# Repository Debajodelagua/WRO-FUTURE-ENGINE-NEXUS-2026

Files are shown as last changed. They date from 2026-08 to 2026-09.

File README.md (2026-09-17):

# 🏎️ WRO 2026 Future Engineers – Team Nexus
<div align="center">
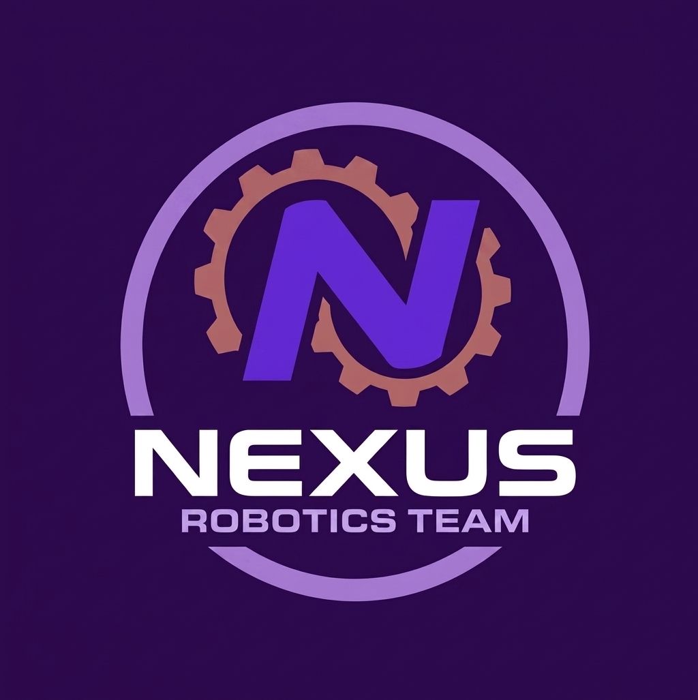
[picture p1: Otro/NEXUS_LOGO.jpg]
Team Nexus Autonomous Vehicle
  
  
  <br><br>
  
  
  
  <br>
  
  
  
  
  <br>
  
  
  
  <br>
  
  

</div>

Nuestro prototipo **"Smoke"** es un vehículo autónomo diseñado para la categoría **Future Engineers de la World Robot Olympiad™ (WRO) 2026**. 
Este documento técnico ha sido elaborado bajo un formato de **libro blanco de ingeniería (*Engineering Whitepaper*)**: no se limita a describir el resultado final, sino que expone de forma analítica y reproducible el **porqué detrás de cada decisión técnica**, los compromisos de diseño (*trade-offs*), los cálculos físicos y la evolución experimental del proyecto. Cualquier equipo o investigador que consulte esta documentación podrá comprender a profundidad los fundamentos cinemáticos, térmicos, eléctricos y de software que rigen el vehículo, permitiendo reproducir o iterar la plataforma de forma integral.

## 📑 Índice General: Módulos de Ingeniería del Proyecto

- [Introducción y Datos del Equipo](#introduccion-equipo)
  - [Filosofía de Trabajo y Metodología de Co-Diseño](#filosofia-trabajo)
  - [Nuestro Equipo (INIAR)](#nuestro-equipo)
  - [Estructura del Repositorio y Ficha Técnica Oficial (225 × 170 × 110 mm, 859 g)](#ficha-tecnica)
  - [Galería de Inspección Técnica 360°](#fotos-360)
  - [Videos Oficiales de Demostración (Open & Obstacle Challenge)](#videos-oficiales)

---

### [Módulo 1: Movilidad y Diseño Mecánico](#modulo-1-movilidad)
- 1.1 [Chasis Modular Multicapa en PETG y Distribución de Masa](#chasis-petg)
- 1.2 [Estructura Rígida, Tornillería Pasante M3 y Separación de Niveles](#separacion-niveles)
- 1.3 [Geometría de Dirección Ackermann Híbrida y Validación de Barrido](#geometria-ackermann)
- 1.4 [Tren Motriz Trasero (RWD), Transmisión Cónica y Caja Diferencial](#tren-motriz)
- 1.5 [Estudio Dinámico: Razonamiento de Par Motor vs. Velocidad](#estudio-dinamico)
- 1.6 [Configuración Escalonada de Ruedas (*Staggered Setup*) e Inercia Rotacional](#ruedas-escalonadas)
- 1.7 [Diseños Alternativos Considerados vs. Diseño Mecánico Elegido](#alternativas-mecanicas)
  - 1.7.1 [Evolución Cronológica y Autopsia Técnica de Prototipos Descartados](#prototipos-descartados)

---

### [Módulo 2: Arquitectura de Energía y Sensores](#modulo-2-energia-sensores)
- 2.1 [Topología de Alimentación Desacoplada en 3 Ramas Independientes](#topologia-alimentacion)
- 2.2 [Presupuesto Energético y Cuadro de Consumo de Corriente (*Power Budget*)](#presupuesto-energetico)
- 2.3 [Banco de Baterías EVE 18650 2S2P (7.0V - 7.4V, 7000 mAh) y Autonomía Teórica](#baterias-18650)
- 2.4 [Regulación de Voltaje: Elevador XL6009 a 14V y Supresión de Caída L298N](#regulacion-voltaje)
  - 2.4.3 [Selección de Conductores: Cable 18 AWG Automotriz y Borneras](#cableado-conductores)
- 2.5 [Selección, Justificación y Ubicación Geométrica de Sensores](#justificacion-sensores)
  - 2.5.1 [Cámara Neuronal HuskyLens 2 (IA / Visión por Color)](#sensor-huskylens)
  - 2.5.2 [Unidad de Medición Inercial MPU6050 (Giroscopio / Acelerómetro)](#sensor-mpu6050)
  - 2.5.3 [Arreglo Perimetral de Ultrasonidos HC-SR04](#sensor-ultrasonicos)
- 2.6 [Métodos de Calibración de Sensores y Procedimiento de Arranque](#calibracion-sensores)
- 2.7 [Esquema Eléctrico Oficial, Pinout y Análisis de Puntos Únicos de Fallo (SPOF)](#esquema-pinout)

---

### [Módulo 3: Arquitectura de Software y Control Autónomo](#modulo-3-software)
- 3.1 [Arquitectura General y Máquina de Estados Finitos (FSM)](#fsm-general)
- 3.2 [Estrategia de Seguimiento de Carril: Open Challenge (`NUMERO4.ino`)](#software-open-challenge)
  - 3.2.1 [Inicialización, Concurrencia y Configuración de Periféricos](#software-setup)
  - 3.2.2 [Percepción Ultrasónica y Detección Dinámica de Esquinas](#software-ultrasonico)
  - 3.2.3 [Control PD de Heading con Giróscopo y Maniobra de Escape](#software-pd)
  - 3.2.4 [Negociación Determinista de Curvas y Conteo de 12 Esquinas](#software-curvas)
- 3.3 [Estrategia de Obediencia a Obstáculos: Obstacle Challenge (`OBSTACULO_2.ino`)](#estrategia-obstaculos)
  - 3.3.1 [Concurrencia Multihilo en FreeRTOS y Odometría Inercial Discreta (Core 0 @ 500 Hz)](#obstaculos-modulo1-inercial)
  - 3.3.2 [Percepción por Visión IA, Filtrado Espacial de Borde y Modo Cazador Proporcional](#obstaculos-modulo2-cazador)
  - 3.3.3 [Pre-Alineación en S ante Desviación Angular y Coreografía Evasiva en 5 Fases](#obstaculos-modulo3-coreografia)
  - 3.3.4 [Bloqueo Global de Sentido de Pista (`direccion_global_pista`) y Fusión Sensorial](#obstaculos-modulo4-bloqueo-fsm)
- 3.4 [Manejo de Casos Extremos, Métricas de Rendimiento y Randomizadores Web](#metricas-rendimiento)
- 3.5 [Modelado Cinemático y Simulación en MATLAB / GNU Octave (Candidatura MathWorks Modeling Award)](#simulacion-matlab)

---

### [Módulo 4: Pensamiento Sistémico y Gestión Integral de Riesgos](#modulo-4-pensamiento-sistemico)
- 4.1 [Interacción Dinámica entre Subsistemas y Filosofía Holística](#interaccion-subsistemas)
- 4.2 [Restricciones Explícitas del Sistema y Compromisos de Diseño (*Trade-offs*)](#restricciones-compromisos)
- 4.3 [Matriz Comparativa: «Por qué elegimos X en lugar de Y»](#matriz-porque-x-en-lugar-de-y)
- 4.4 [Limitaciones del Robot y Compensaciones (Efecto de Iluminación en Visión de Valencia)](#limitaciones-compensaciones)
- 4.5 [Matriz de Identificación, Gestión y Mitigación de Riesgos](#mitigacion-riesgos)
- 4.6 [Ciclos de Iteración y Diario de Ingeniería (Resolución de Fallas Críticas)](#diario-ingenieria)

---

### [Módulo 5: Reproducibilidad, Guía de Construcción y Control de Calidad](#modulo-5-reproducibilidad)
- 5.1 [Lista Maestra de Materiales (BOM) y Mini-Datasheets de Componentes](#bom)
- 5.2 [Guía de Construcción Paso a Paso del Robot (*Step-by-Step Build Guide*)](#guia-construccion)
- 5.3 [Entorno de Software, Versiones de Librerías y Procedimiento de Flasheo](#entorno-software)
- 5.4 [Flujo de Trabajo de Pruebas en Pista y Protocolo de Calibración](#protocolo-pruebas)
- 5.5 [Estructura del Repositorio, Control de Versiones y Notas de Lanzamiento](#control-versiones)

# 🏁 Introducción y Datos del Equipo 

## Filosofía de Trabajo y Metodología de Co-Diseño 
En el **Instituto de Inteligencia Artificial y Robótica del estado Zulia (INIAR)**, el desarrollo de **"Smoke"** no se abordó como una suma de tareas aisladas, sino bajo un **modelo holístico de ingeniería concurrente**:
```mermaid
flowchart TD
    OBJ["🎯 Objetivo Común: Desempeño Robusto en WRO 2026"] --> DISCUSS["🧠 Lluvia de Ideas y Bocetos Preliminares"]
    DISCUSS --> CAD["⚙️ Modelado CAD Paramétrico\n(Fusion 360)"]
    DISCUSS --> ELEC["⚡ Arquitectura y Esquemáticos\n(Fritzing)"]
    DISCUSS --> CODE["💻 Firmware No Bloqueante\n(Arduino IDE + FreeRTOS)"]
    
    CAD & ELEC & CODE --> TEST["🏁 Validación Incremental en Pista de Pruebas"]
    
    TEST -->|"Falla o Comportamiento Irregular"| TRIAGE["🔍 Triaje Conjunto de Falla\n(Todo el equipo analiza la causa raíz)"]
    TRIAGE --> DISCUSS
    classDef main fill:#0366d6,stroke:#24292e,stroke-width:2px,color:#fff;
    classDef step fill:#1f2328,stroke:#58a6ff,stroke-width:1px,color:#c9d1d9;
    classDef fail fill:#d73a49,stroke:#24292e,stroke-width:2px,color:#fff;
    class OBJ main;
    class DISCUSS,CAD,ELEC,CODE,TEST step;
    class TRIAGE fail;
```

## Nuestro Equipo (INIAR) 
Team Nexus está integrado por estudiantes universitarios del **Instituto de Inteligencia Artificial y Robótica del estado Zulia "Dr. Héctor Rafael Rojas" (INIAR)**, combinando experiencia práctica en torneos nacionales y mundiales:

| 📸 Fotografía Oficial del Equipo | 🤪 Detrás de Cámaras: El Estrés de Boxes y Pasión en Pista |
| :---: | :---: |
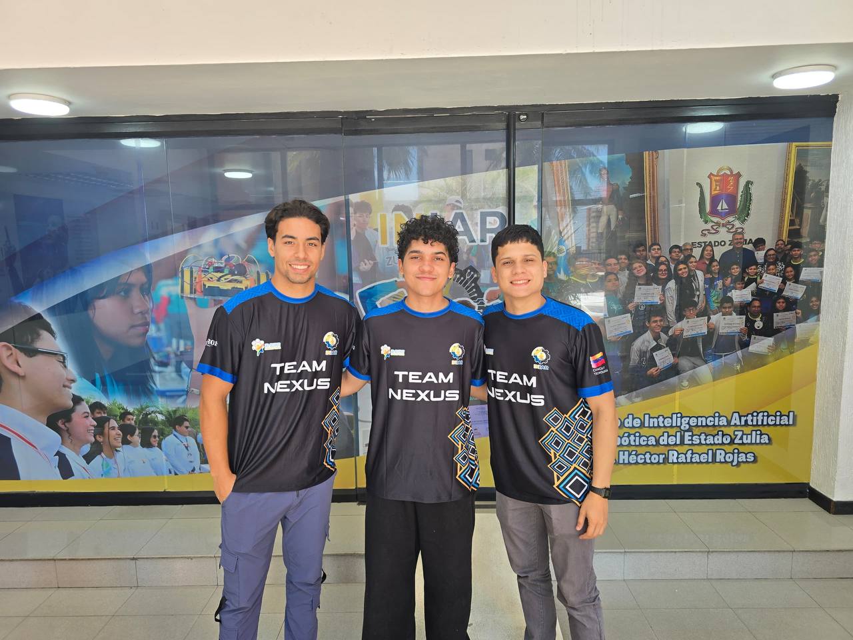
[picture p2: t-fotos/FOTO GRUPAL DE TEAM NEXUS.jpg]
Fotografía Oficial Team Nexus INIAR
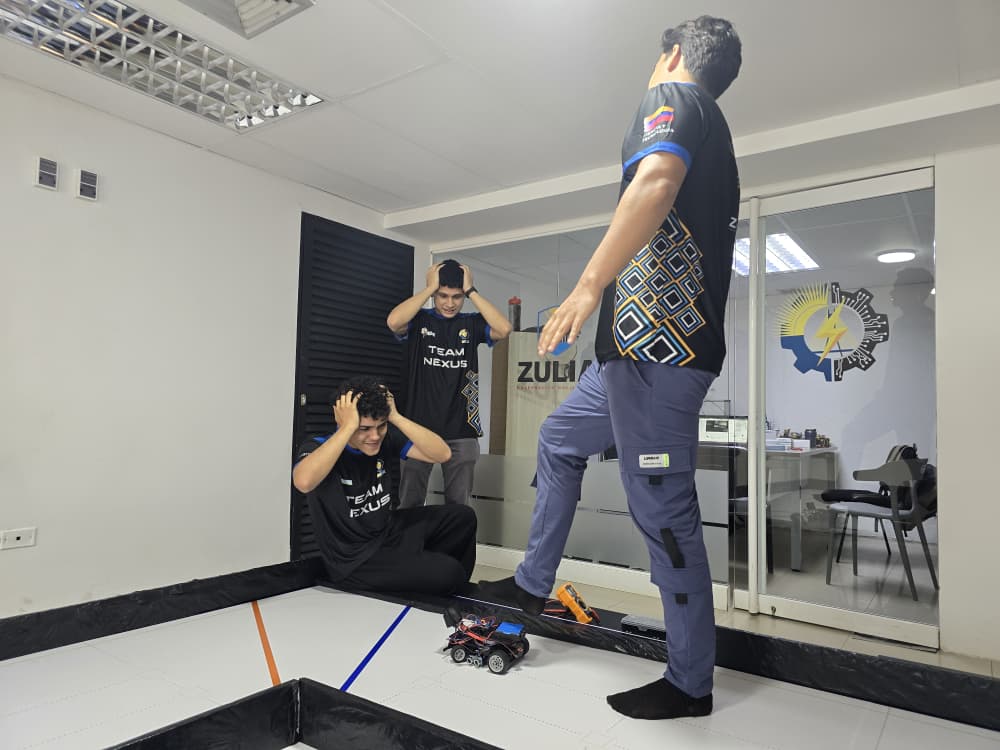
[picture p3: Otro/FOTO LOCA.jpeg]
Detrás de Cámaras Team Nexus en Pista
|  |  |
| *Team Nexus en el laboratorio de robótica de INIAR (Zulia, Venezuela).* | *Momentos de adrenalina y humor durante los ensayos en pista: ¡cuidando a "Smoke" de no ser pisado en plena calibración de giros!* |

<br>

### 👤 David Ocando 
**Líder de Arquitectura Eléctrica, Gestión de Potencia y Co-Administrador Digital**
<div align="center">
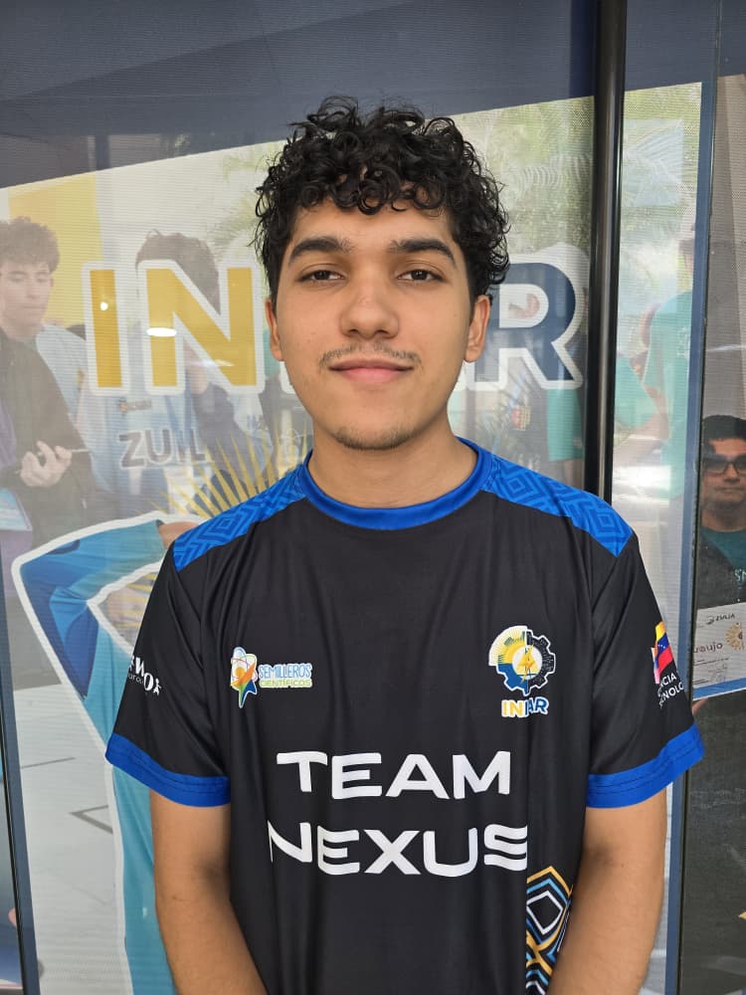
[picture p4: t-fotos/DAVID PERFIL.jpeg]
David Ocando
  
</div>

* **Formación Académica:** Estudiante de Ingeniería Eléctrica (Mención Generación y Distribución de Potencia) – **Universidad Rafael Urdaneta (URU)**.
* **Responsabilidades Técnicas en "Smoke":**
  * **Diseño Eléctrico de Potencia:** Cálculo de caídas de tensión, selección de convertidores DC-DC y desacoplamiento en 3 ramas independientes (lógica a 5V, actuadores a 5V y tracción a 14V).
  * **Almacenamiento Energético:** Configuración del banco de celdas 18650 (2S2P / 7000 mAh), monitoreo de curvas de descarga y dimensionamiento de cables de potencia.
  * **Inmunidad Electromagnética:** Unificación del plano de masas (Common Ground), filtrado de ruidos parásitos de conmutación y protocolo de encendido seguro.
  * **Documentación Técnica:** Mantenimiento y estandarización del repositorio en GitHub bajo la rúbrica oficial de la WRO.
#### 🏆 Historial de Competición:
* **Copa KAI (2023):** Participación en robótica móvil y combate autónomo.
* **FIRST Tech Challenge (FTC Championship – Piacenza, Italia 2024):** Representación internacional de Venezuela; desarrollo de sistemas de potencia de alta corriente y actuadores de respuesta rápida.
* **WRO Venezuela (Temporada 2025):** Competidor oficial en la categoría **RoboSports**, optimizando la respuesta dinámica y la robustez eléctrica del robot en cancha.
---
### 👤 José Montiel 
**Ingeniero Líder de Firmware, Visión Artificial y Control Autónomo**
<div align="center">
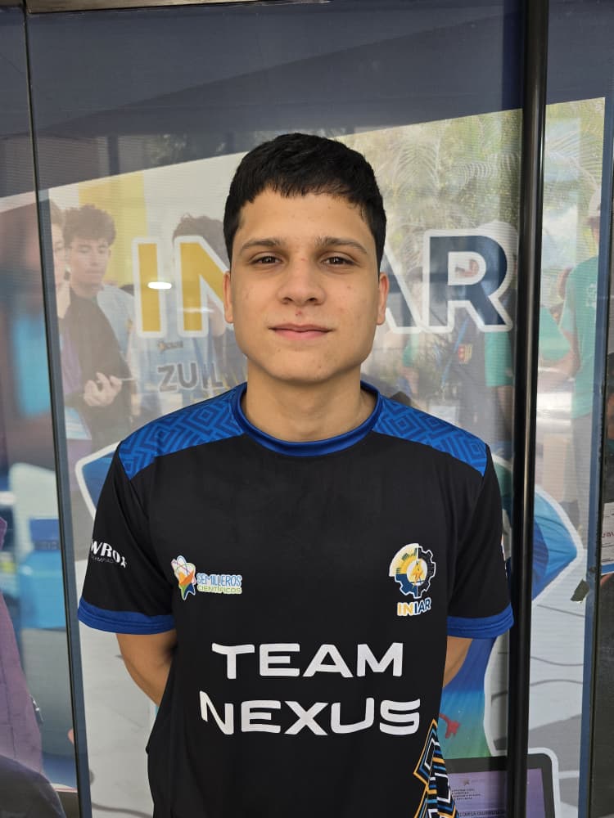
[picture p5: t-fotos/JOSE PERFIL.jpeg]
José Montiel
  
</div>

* **Formación Académica:** Estudiante de Ingeniería Electrónica – **Universidad Dr. Rafael Belloso Chacín (URBE)**.
* **Responsabilidades Técnicas en "Smoke":**
  * **Desarrollo de Firmware Embebido:** Programación en C++ sobre ESP32-S3 bajo arquitectura no bloqueante con temporizadores de hardware.
  * **Sistemas Operativos en Tiempo Real:** Implementación de tareas dedicadas en **FreeRTOS** (Core 0 para la integración angular del MPU6050 a 500 Hz y Core 1 para la navegación).
  * **Control de Rumbo y Estabilidad:** Algoritmo Proporcional-Derivativo (PD) con zona muerta y compensación angular de escape lateral ante muros.
  * **Visión por Computador:** Calibración y enlace serie UART (115,200 baudios) con la cámara **HuskyLens 2** para la clasificación colorimétrica de obstáculos.
  * **Tolerancia a Fallas:** Desarrollo del mecanismo de auto-rescate en caliente del bus I2C mediante 9 ciclos de reloj forzados en SCL.
#### 🏆 Historial de Competición:
* **WRO Venezuela Regional (Temporada 2025):** Participación oficial en la categoría **Future Engineers**, acumulando experiencia en cinemática de pista, algoritmos reactivos y visión de carril.
---
### 👤 Jairo Cruz 
**Ingeniero de Diseño Mecánico, Dinámica Vehicular y Manufactura Aditiva**
<div align="center">
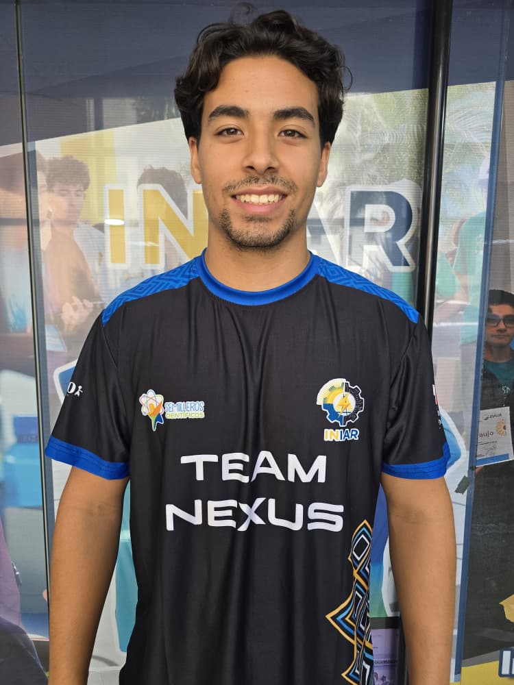
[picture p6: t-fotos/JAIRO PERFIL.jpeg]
Jairo Cruz
  
</div>

* **Formación Académica:** Estudiante de Ingeniería Electrónica (Mención Automatización y Control).
* **Responsabilidades Técnicas en "Smoke":**
  * **Diseño Paramétrico 3D:** Modelado en **Autodesk Fusion 360** del chasis modular de tres niveles, bancada de motor y soportes de sensado.
  * **Manufactura Aditiva Avanzada:** Optimización de laminado en **Bambu Lab** con filamento **PETG** estructural (orientación de capas, 100% infill en engranajes y tolerancias dimensionales).
  * **Cinemática y Ensamblaje:** Adaptación del piñón cónico con entrada D-Shaft al diferencial trasero, timonería Ackermann y estandarización métrica M3.
#### 🏆 Historial de Competición:
* **Copa KAI (2023):** Competidor en diseño de chasis ultraligero y robótica móvil.
* **FIRST Tech Challenge (FTC Championship – Italia 2024):** Integrante de la delegación internacional venezolana; diseño de sistemas de reducción mecánica y ensamblaje de alta precisión.
* **WRO Venezuela (Temporada 2025):** Competidor en la categoría **RoboSports**, especializándose en rigidez torsional y resistencia a impactos mecánicos.
---
### 👤 Ing. Wender Sánchez 
**Mentor Líder y Asesor de Ingeniería Mecánica**
<div align="center">
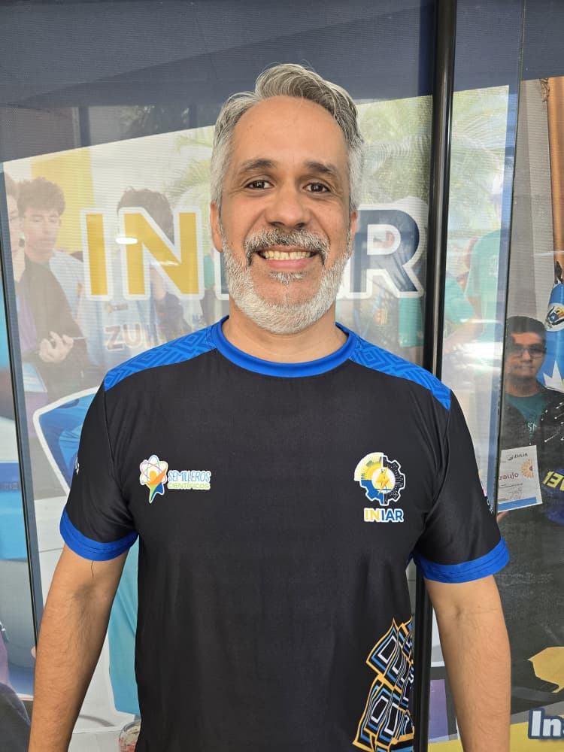
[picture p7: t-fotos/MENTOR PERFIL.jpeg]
Ing. Wender Sánchez
  
</div>

* **Formación y Perfil:** Ingeniero Mecánico egresado de la **Universidad del Zulia (LUZ)**, con dilatada trayectoria profesional en dinámica de vehículos, cinemática de mecanismos y sistemas de transmisión de potencia.
* **Acompañamiento Metodológico:** Supervisión técnica en el cálculo analítico de fuerzas, validación de relaciones de transmisión, selección de materiales termoplásticos y apego a la rúbrica internacional de la WRO.

## Ficha Técnica Oficial de la Plataforma "Smoke" (225 × 170 × 110 mm, 859 g)
<div align="center">
  
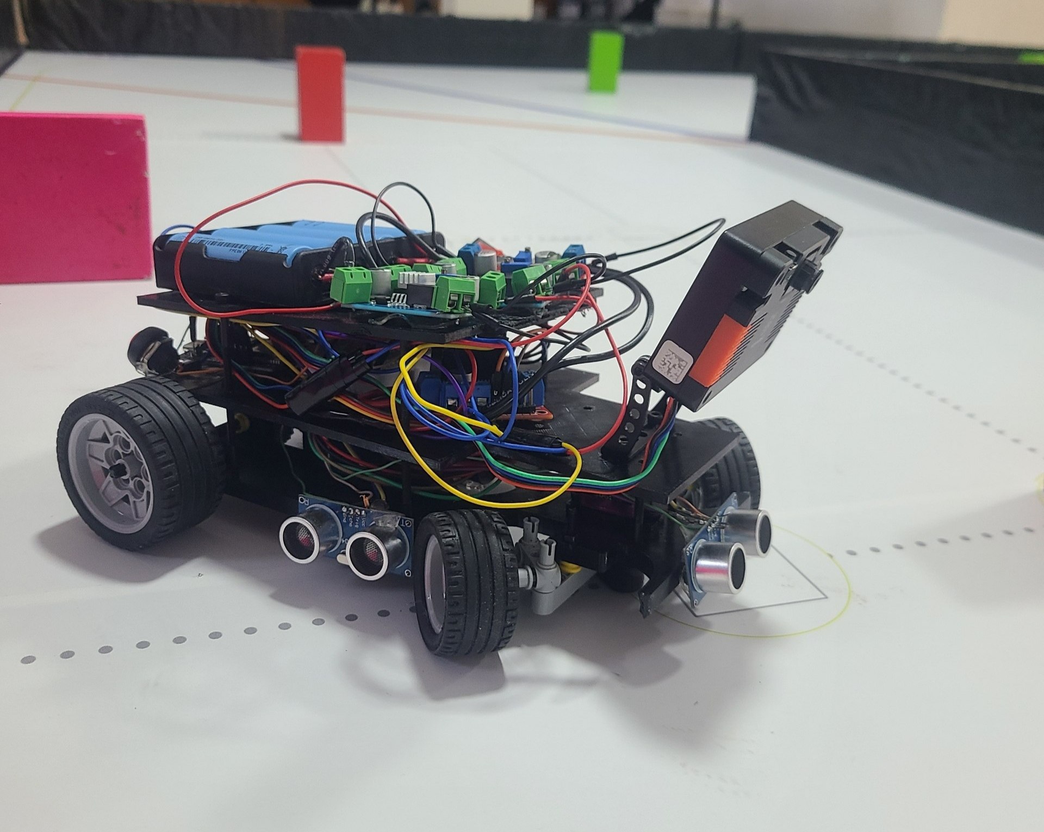
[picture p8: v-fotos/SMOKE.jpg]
Vehículo Autónomo Smoke
  
  <br>
  
  <i>Plataforma robótica autónoma "Smoke" en configuración de pista para WRO 2026.</i>
</div>
<br>

El diseño dimensional y dinámico de **"Smoke"** responde a una búsqueda deliberada de compacidad y bajo momento de inercia rotacional ($I_z$), priorizando la agilidad en curvas cerradas sobre estructuras voluminosas:
* **📐 Dimensiones Geométricas Reales:** 
  * Longitud total ($L_{total}$): **225 mm** ($22.5\text{ cm}$)
  * Anchura de vía con neumáticos ($W_{total}$): **170 mm** ($17.0\text{ cm}$)
  * Altura máxima a la cúpula de potencia ($H_{total}$): **110 mm** ($11.0\text{ cm}$)
  * *Conformidad Reglamentaria:* Cumple con amplio margen la restricción dimensional oficial de la WRO ($< 300 \times 200 \times 300\text{ mm}$), dejando un margen de seguridad de $75\text{ mm}$ en longitud y $30\text{ mm}$ en anchura para evitar roces con los muros en giros cerrados.
* **⚖️ Masa y Balística Dinámica:** 
  * Masa total verificada en báscula de laboratorio: **859 gramos** ($0.859\text{ kg}$).
  * Peso total efectivo sobre el tapiz: 
    $$P = m \cdot g = 0.859\text{ kg} \times 9.81\text{ m/s}^2 \approx \mathbf{8.43\text{ Newtons}}$$
  * *Ventaja Dinámica del Peso Contenido:* Con apenas 859 g (frente a prototipos convencionales de la categoría que superan los 1150 g), la inercia lineal ($F = m \cdot a$) y centrífuga ($F_c = m \cdot \frac{v^2}{R}$) se reducen en más de un 25%, permitiendo desaceleraciones más tardías antes de la curva y aceleraciones en recta mucho más explosivas sin sobrecalentar el motor Makeblock.
* **🧠 Unidad Central de Cómputo:** **ESP32-S3 DevKit** (Dual-Core Xtensa LX7 240 MHz, 512 KB SRAM interna) operando bajo **FreeRTOS** para la ejecución concurrente de telemetría inercial y control reactivo.
* **👁️ Percepción Sensorial y Visión IA:** 
  * Procesador de visión inteligente **HuskyLens 2** en enlace serie UART por hardware a 115,200 baudios.
  * Red perimetral de **3 transductores ultrasónicos HC-SR04** ubicados a cota rasante.
  * Unidad de Medición Inercial (**IMU MPU6050**) concéntrica con el centro de masa del vehículo.
* **🦾 Dinámica, Dirección y Tracción:** 
  * Dirección delantera **Ackermann Híbrido** con servomotor digital metálico **TowerPro MG90S**.
  * Propulsión trasera **RWD** impulsada por un motor DC **Makeblock 9V (185 RPM nominales con encoder de cuadratura integrado)**, acoplado mediante transmisión cónica a 90° de PETG a una caja diferencial trasera de 3 satélites cónicos.
* **🔋 Subestación Energética:** Banco de celdas cilíndricas de litio **18650 (3.5V / 3500 mAh)** en configuración **2S2P** (tensión de bus nominal de 7.0V y capacidad masiva de **7000 mAh**), con 3 etapas DC-DC de regulación independiente (XL4015, LM2596 y XL6009).
> [!NOTE]
> **Origen del Nombre "Smoke":**
> Durante las primeras fases de validación experimental en el banco de potencia del laboratorio de INIAR, severos retornos inductivos y picos de sobretensión provocados por la conmutación del motor quemaron consecutivamente tres módulos reguladores *Step-Down*, despidiendo una densa columna de humo blanco. 
> 
> Lejos de desalentarnos, este suceso marcó el rumbo de nuestra ingeniería: nos impulsó a rediseñar de raíz toda la arquitectura eléctrica, aislando la lógica de la potencia mediante 3 ramas independientes y unificando el plano de masas. Bautizar al vehículo como **"Smoke"** rinde tributo a la resiliencia en el taller: cada falla es un aprendizaje indispensable para alcanzar la máxima fiabilidad en pista.
<p align="right"><a href="#indice-general">⬆️ Volver al Índice</a></p>

## Galería de Inspección Técnica 360°
Para verificar la simetría estructural, la concentricidad del centro de masa ($CoG$), la rigidez de la manufactura aditiva en PETG y el despeje libre sobre el tapiz (*ground clearance*), se documentan los **6 perfiles de inspección ortogonal reglamentarios**:
| 📸 Perfil de Inspección | 🖼️ Registro Visual | 🔍 Criterio de Verificación Técnica de Ingeniería |
| :--- | :--- | :--- |
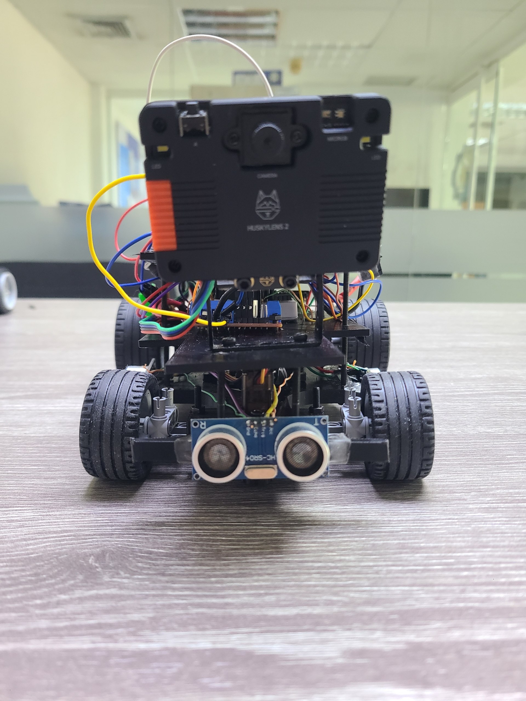
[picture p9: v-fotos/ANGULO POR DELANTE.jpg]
Perfil Delantero
| **Vista Frontal**<br>*(Front View)* |  | • Evalúa la orientación e inclinación angular del procesador de visión **HuskyLens 2** en el Piso 2.<br>• Muestra la posición del sensor ultrasónico central delantero para el frenado ante esquinas a 70 cm.<br>• Inspección del paralelismo de las manguetas de dirección y el despeje del parachoques. |
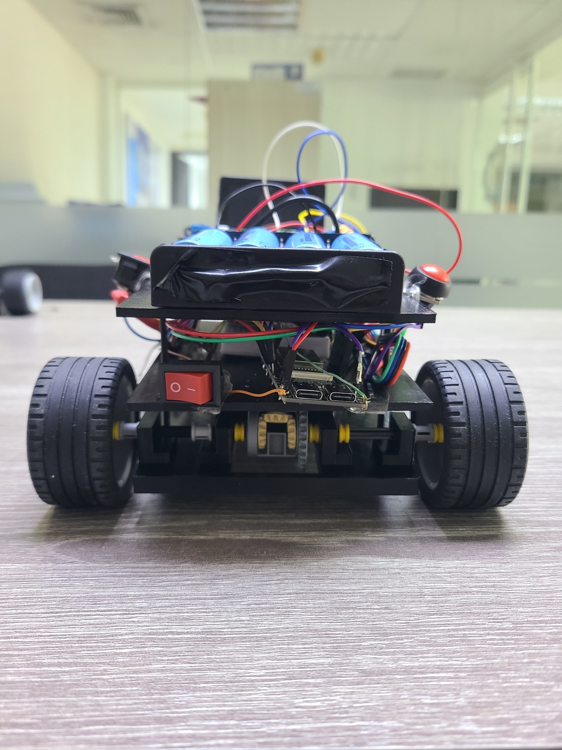
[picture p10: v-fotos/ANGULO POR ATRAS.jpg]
Perfil Trasero
| **Vista Trasera**<br>*(Rear View)* |  | • Evidencia el anclaje del motor Makeblock sobre su bancada de PETG reforzada con 8 tornillos M3.<br>• Muestra el ensamble de la transmisión cónica atacando la corona del diferencial trasero.<br>• Verificación de los bujes y retenedores axiales de eje que evitan el desplazamiento transversal de las ruedas de tracción de 43 mm. |
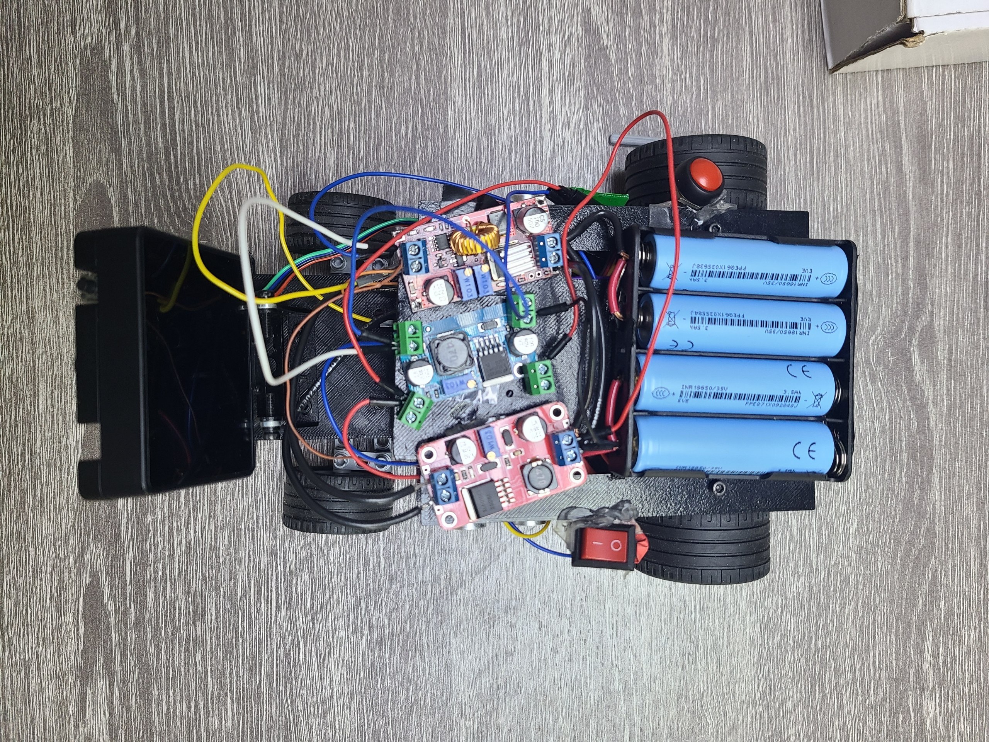
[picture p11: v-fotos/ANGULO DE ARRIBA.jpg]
Perfil Superior
| **Vista Superior**<br>*(Top View)* |  | • Evalúa el balance transversal de masas: banco 18650 (2S2P) a la par de los módulos Buck/Boost.<br>• Inspección de la posición concéntrica del sensor inercial **MPU6050** en el centro geométrico del chasis.<br>• Muestra la segregación y peinado del cableado de potencia y señales lógicas hacia el ESP32-S3. |
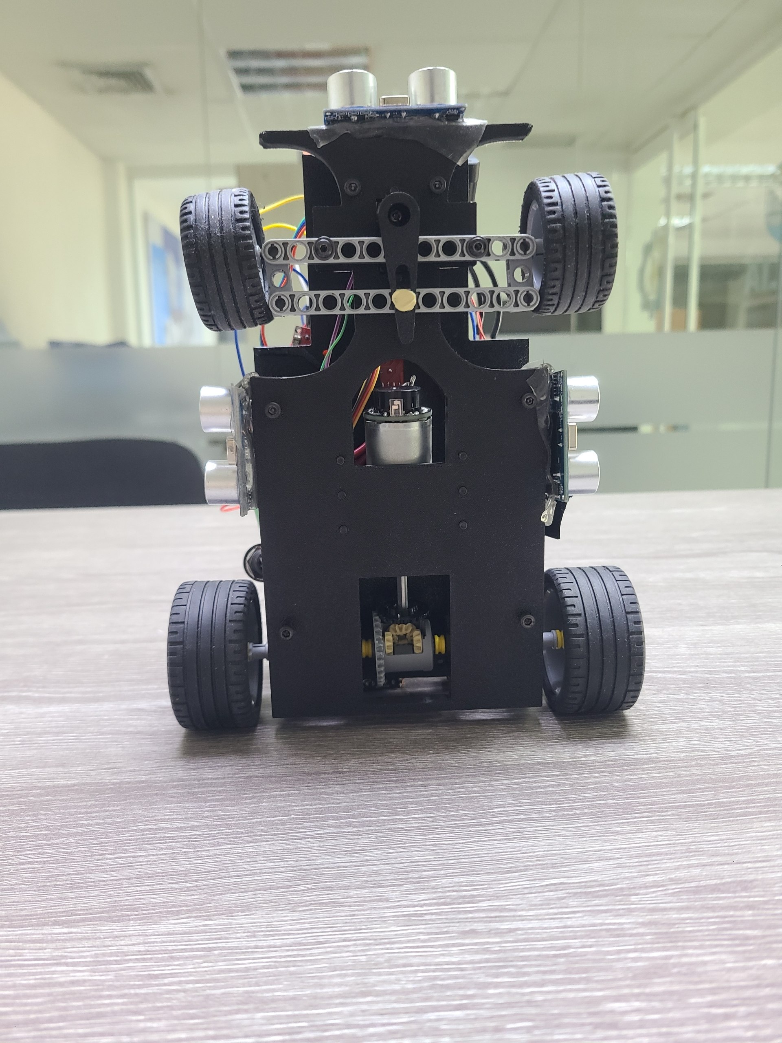
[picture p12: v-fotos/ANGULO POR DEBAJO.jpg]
Perfil Inferior
| **Vista Inferior**<br>*(Bottom View)* |  | • Comprueba la superficie lisa del primer piso en PETG para minimizar la resistencia aerodinámica.<br>• Verificación del *ground clearance* ($\ge 15\text{ mm}$) para evitar cualquier roce en el paso por desniveles del tapiz.<br>• Muestra las cavidades hexagonales empotradas para tuercas de seguridad autoblocantes M3. |
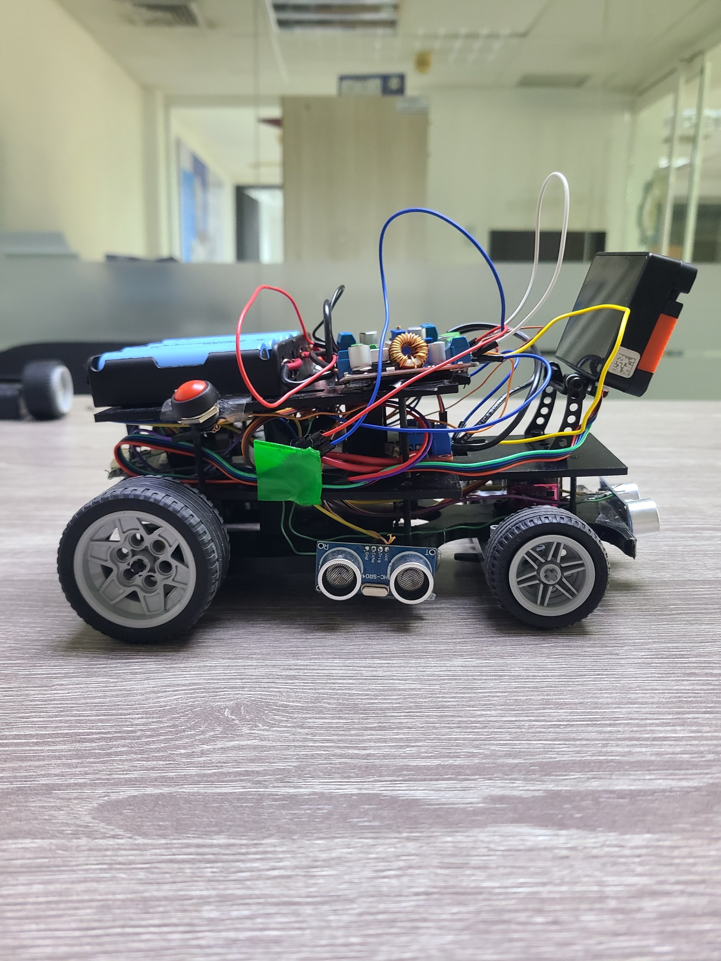
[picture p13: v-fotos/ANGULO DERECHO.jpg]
Perfil Derecho
| **Vista Lateral Derecha**<br>*(Right View)* |  | • Evidencia la separación vertical física estricta entre el Piso 1 (tracción), Piso 2 (lógica) y Piso 3 (potencia).<br>• Muestra la orientación perpendicular del sensor ultrasónico lateral derecho para el centrado a 30 cm.<br>• Inspección del escalonamiento de neumáticos: Ø 30 mm directrices y Ø 43 mm motrices. |
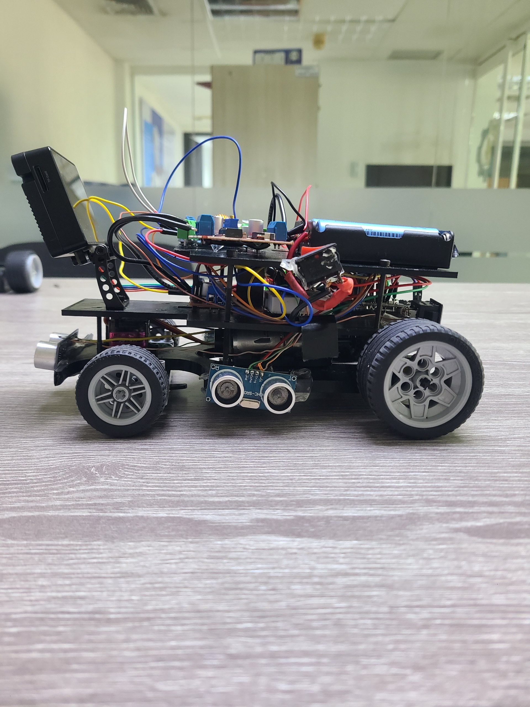
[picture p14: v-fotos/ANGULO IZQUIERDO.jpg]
Perfil Izquierdo
| **Vista Lateral Izquierda**<br>*(Left View)* |  | • Permite verificar el acceso a la interfaz de usuario: doble switch maestro y pulsador de arranque GPIO 21.<br>• Disposición del sensor ultrasónico lateral izquierdo.<br>• Evidencia la ventilación pasiva del disipador de aluminio del driver L298N y los reguladores de potencia. |
<p align="right"><a href="#indice-general">⬆️ Volver al Índice</a></p>

## Videos Oficiales de Demostración (Open & Obstacle Challenge)
Para validar de forma fehaciente el cumplimiento del reglamento internacional de la WRO, se presentan los registros audiovisuales de la plataforma "Smoke" operando en pista reglamentaria:

### Ronda Abierta (Open Challenge - Recorrido Completo de 3 Vueltas)
Demostración del vehículo completando de manera 100% autónoma las 12 esquinas reglamentarias (3 vueltas continuas), navegando mediante la fusión de la red ultrasónica perimetral y la telemetría inercial del MPU6050:
<div align="center">
  <a href="https://youtu.be/ooOyRUvQE2Y" target="_blank">
    Video Ronda Abierta Team Nexus
    <br>
    <b>▶️ Ver en YouTube: Ronda Abierta Oficial – Team Nexus (WRO 2026)</b>
  </a>
</div>
<br>

### Ronda de Obstáculos (Obstacle Challenge - Evasión y Desempeño)
Demostración técnica de la clasificación en tiempo real de los bloques de tráfico (rojos y verdes) mediante el procesador de visión inteligente **HuskyLens 2** en enlace serie UART, inyectando de forma inmediata la maniobra de viraje evasivo hacia el servomotor MG90S con realineación angular:

<div align="center">
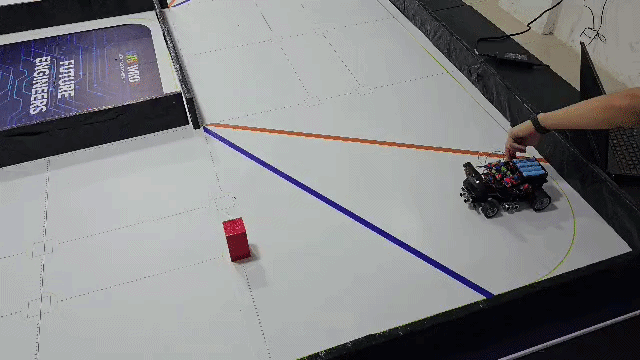
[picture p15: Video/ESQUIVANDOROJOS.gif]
Evasión Dinámica de Bloque Rojo
  
  <br>
  <b>📹 Demostración Técnica: Detección colorimétrica y maniobra autónoma de esquiva ante bloque reglamentario rojo (ID 1)</b>
  <br><br>
  <a href="https://youtu.be/E-C2RvofRqQ" target="_blank">
    Video Demostración Obstacle Challenge Nexus
    <br>
    <b>▶️ Ver en YouTube: Ronda de Obstáculos Oficial – Team Nexus (WRO 2026)</b>
  </a>
</div>

# 🏎️ Módulo 1: Movilidad y Diseño Mecánico 

El chasis y tren cinemático de **"Smoke"** fueron desarrollados bajo un enfoque híbrido de manufactura: combinando piezas estructurales modeladas en Autodesk Fusion 360 e impresas en PETG con componentes de articulación de bajo rozamiento e inyección de alta precisión, garantizando resistencia, ligereza y exactitud dimensional.
Esta arquitectura fue calculada específicamente para soportar las fuerzas de inercia y torsión generadas por una masa dinámica de **859 gramos**, optimizando la posición del centro de gravedad ($CoG$) y minimizando la fricción en pista.

## 1.1 Chasis Modular Multicapa en PETG y Distribución de Masa 
Para evitar el desorden estructural y blindar la electrónica contra interferencias electromagnéticas (EMI) y calor, el vehículo implementa una **estructura vertical de tres estratos segregados**:

```mermaid
flowchart TD
    subgraph "PISO 3: ALIMENTACIÓN Y GESTIÓN ENERGÉTICA"
        P3["🔋 Banco Celdas EVE 18650 2S2P (7000 mAh 7.0V)<br>⚡ Convertidores DC-DC: XL4015 (5V), LM2596 (5V) y XL6009 (14V)<br>🔌 Doble Switch de Seguridad Maestro"]
    end
    subgraph "PISO 2: CONTROL CENTRAL, VISIÓN IA Y TELEMETRÍA"
        P2["🧠 Microcontrolador Central ESP32-S3 DevKit<br>👁️ Procesador de Visión Inteligente HuskyLens 2<br>🧭 Sensor Inercial IMU MPU6050 (Alineado al CoG)<br>🔲 Driver Puente H L298N con Disipador Térmico"]
    end
    subgraph "PISO 1: DINÁMICA DE TRACCIÓN Y CONTACTO AL SUELO"
        P1["⚙️ Motor Makeblock 9V (185 RPM) + Bancada M3 en PETG<br>🔄 Transmisión Cónica 90° + Caja Diferencial Cónica (3 Satélites)<br>🦾 Dirección Ackermann Híbrida + Servo TowerPro MG90S<br>📡 Red de 3 Sensores Ultrasónicos HC-SR04 (Rasantes)"]
    end
    P3 === P2
    P2 === P1
    classDef n3 fill:#1f2328,stroke:#f85149,stroke-width:2px,color:#fff;
    classDef n2 fill:#1f2328,stroke:#0366d6,stroke-width:2px,color:#fff;
    classDef n1 fill:#1f2328,stroke:#2ea44f,stroke-width:2px,color:#fff;
    class P3 n3;
    class P2 n2;
    class P1 n1;
```

## 1.2 Estructura Rígida, Tornillería Pasante M3 y Separación de Niveles 
Uno de los criterios esenciales para garantizar la fiabilidad del vehículo ante vibraciones de alta frecuencia provocadas por el motor Makeblock y los impactos en pista fue la **unificación total de fijaciones bajo métrica M3**:
<div align="center">
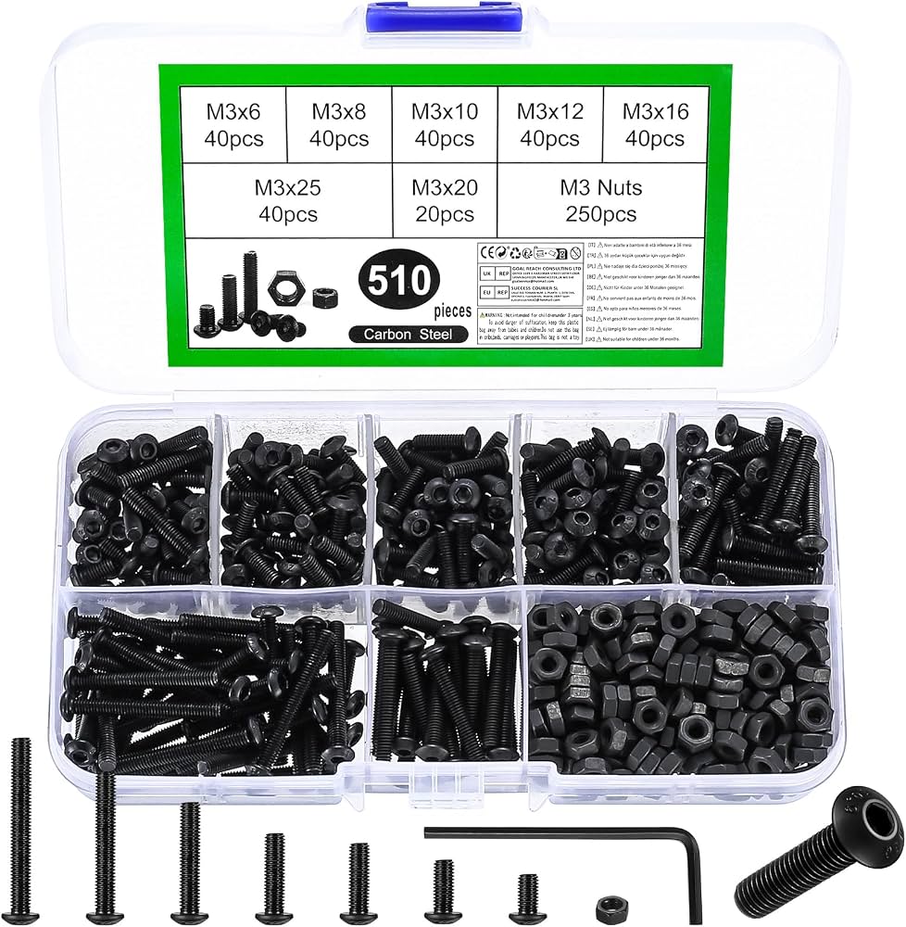
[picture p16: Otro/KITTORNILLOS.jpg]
Kit de Tornillería y Fijaciones M3
  
  <br>
  <i>Kit estandarizado de tornillería métrica M3, tuercas de seguridad autoblocantes y columnas pasantes.</i>
</div>

* **Tornillería Métrica M3:** Se estandarizó el uso de tornillos de acero grado 10.9 con cabeza Allen en longitudes calibradas de **8, 12, 16 y 20 mm** para componentes internos, permitiendo que una sola llave Allen de 2.5 mm opere todo el vehículo en boxes.
* **Columnas Pasantes de 35 mm para Rigidez Inter-Pisos:** 
  Para unir rígidamente los tres pisos del chasis sin depender de pequeñas uniones intermedias que pudieran falsearse con el movimiento, se implementaron **tornillos largos pasantes M3 de 35 mm**:
  * Estos tornillos atraviesan separadores cilíndricos en PETG que fijan con precisión la luz vertical entre niveles: un espacio libre de **$15\text{ mm}$ entre el Piso 1 y el Piso 2** (para dar cabida rasante al motor y servo), y un despeje de **$19\text{ mm}$ entre el Piso 2 y el Piso 3** (para albergar el disipador del L298N, la HuskyLens 2 y el cableado de la IMU).
  * Este diseño en columna pasante distribuye las cargas de flexión a lo largo de toda la altura del vehículo ($110\text{ mm}$), evitando el pandeo estructural.
* **Tuercas de Seguridad Autoblocantes (Nyloc):** Cada unión crítica y remate de las columnas de 35 mm incorpora tuercas con inserto elástico de nylon alojadas en cavidades hexagonales empotradas en el PETG, eliminando por completo la posibilidad de aflojamiento por resonancia mecánica.

<div align="center">
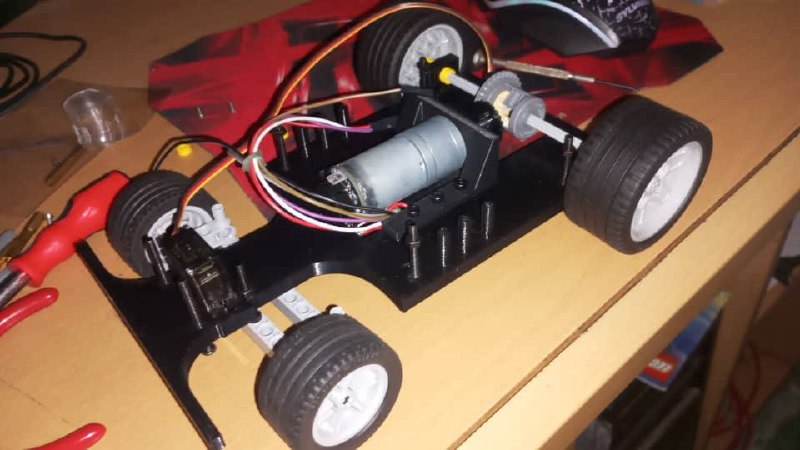
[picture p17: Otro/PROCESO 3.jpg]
Ensamble del Chasis Rodante Base Piso 1
  
  <br>
  <i><b>Figura 1.2:</b> Chasis rodante base (Piso 1) completamente ensamblado en banco de trabajo: integración de la placa inferior en PETG, bancada de motor Makeblock, timonería de dirección Ackermann con servomotor TowerPro MG90S, engranajes cónicos atacando la caja diferencial trasera y las columnas pasantes M3 listas para recibir los niveles intermedio y superior.</i>
</div>

## 1.3 Geometría de Dirección Ackermann Híbrida y Validación de Barrido 

### 1.3.1 Principio Físico y Necesidad Dinámica
Cuando un vehículo traza una curva, la rueda directriz interior recorre un radio de giro más cerrado ($R_i$) que la rueda exterior ($R_o$). Si ambas ruedas giraran al mismo ángulo (geometría paralela convencional), los neumáticos se verían forzados a arrastrarse de lado sobre la pista (*wheel scrub* o arrastre lateral), lo que genera:
1. Una fuerza de fricción parásita que frena el vehículo en cada curva.
2. Pérdida crítica de adherencia en el tren delantero, provocando subviraje (*understeer*).
3. Sobrecarga de corriente y calentamiento prematuro en el servomotor.
Para resolver esto, **"Smoke"** implementa una **geometría de dirección Ackermann**, donde la timonería hace que **la rueda interior gire más pronunciadamente ($\theta_i$) que la exterior ($\theta_o$)**:

| 1. Principio Teórico | 2. Diseño CAD en Fusion 360 | 3. Ensamble Físico en Piso 1 |
| :---: | :---: | :---: |
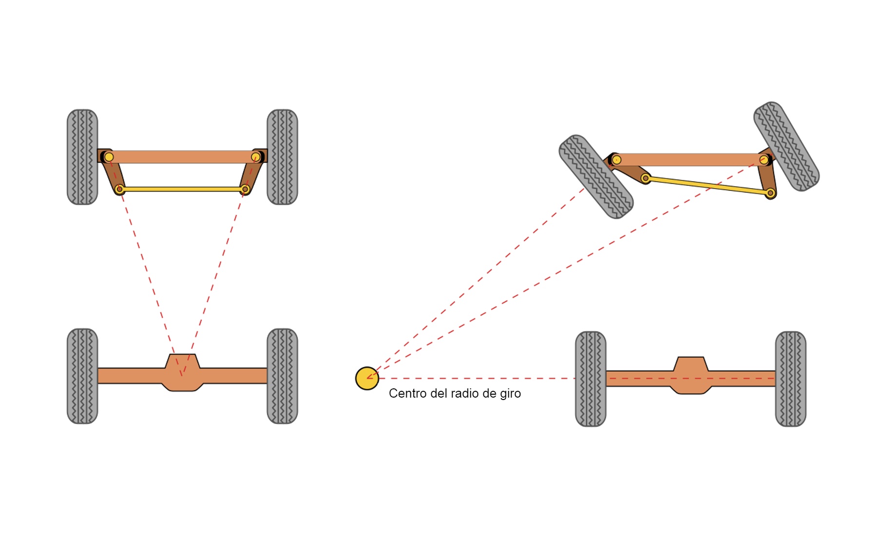
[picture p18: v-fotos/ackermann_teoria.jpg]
Esquema Teórico Ackermann
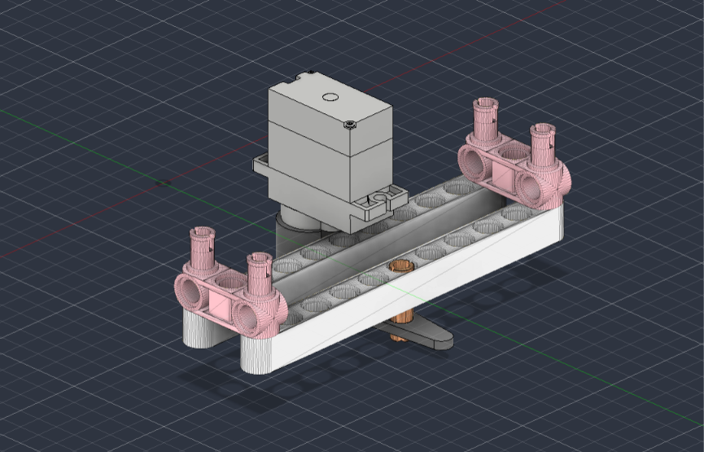
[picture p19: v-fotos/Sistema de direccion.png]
Modelo CAD de Dirección
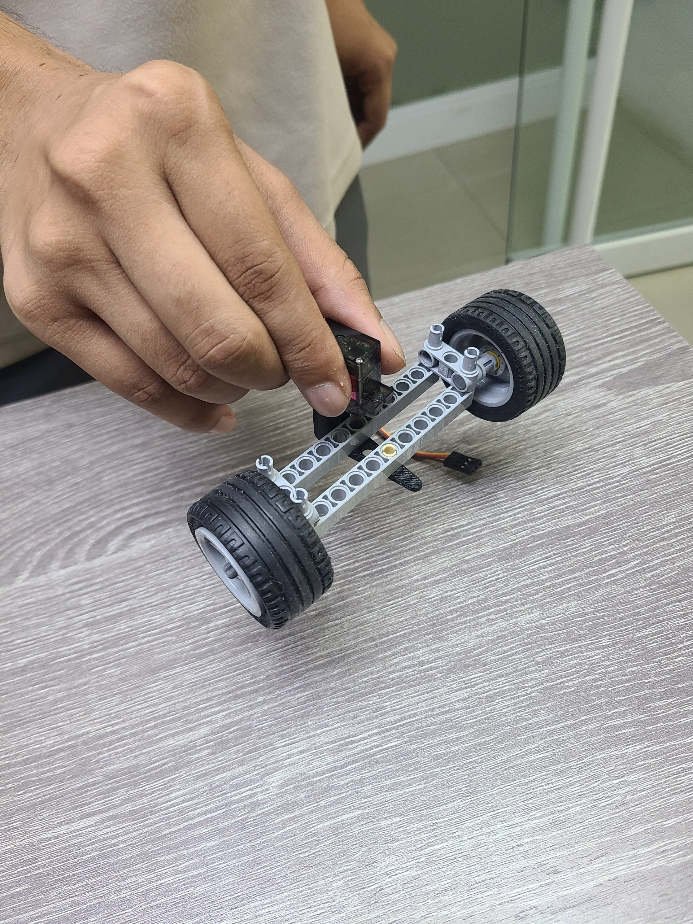
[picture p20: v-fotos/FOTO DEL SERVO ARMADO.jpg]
Ensamble Físico en Chasis
|  |  |  |
| *Convergencia hacia el eje trasero* | *Brazo custom en PETG + manguetas* | *Integración con servo MG90S* |

### 1.3.2 Solución de Co-Diseño: Manguetas de Dirección Inyectadas + Brazo de Servo (*Servo Horn*) Custom en PETG
Durante las fases de prototipado inicial, evaluamos imprimir las manguetas y tirantes de dirección completamente en 3D. Sin embargo, las piezas pequeñas impresas en FDM presentaban microporosidad superficial, lo que generaba un rozamiento irregular y juego mecánico acumulado (*backlash*).

> [!NOTE]
> **Decisión de Ingeniería Híbrida:**
> Optamos por una solución eficiente y probada:
> - **Manguetas y Rótulas de Giro:** Para estos componentes tomamos como inspiración los sistemas modulares inyectados tipo LEGO, ya que proporcionan una superficie de giro suave con fricción casi nula y tolerancias difíciles de igualar en piezas tan pequeñas impresas en 3D.
> - **Brazo de Servo (*Servo Horn*) Custom en PETG:** Diseñado por nosotros a medida en **Autodesk Fusion 360** e impreso con **100% de relleno sólido en PETG**, conectando rígidamente el estriado metálico del servo TowerPro MG90S con la barra de dirección.

#### Anatomía y Justificación del Rediseño del Brazo de Servo (`Modelos/Servor Arm.stl` / `v-fotos/BRAZOSERVO.jpg`)
Los brazos comerciales que vienen de fábrica con el servomotor TowerPro MG90S resultaban totalmente incompatibles con las exigencias dinámicas del vehículo **"Smoke"**:
1. **Longitud Insuficiente y Falta de Recorrido:** Los brazos estándar de nylon son excesivamente pequeños ($\approx 12\text{--}15\text{ mm}$ de radio de palanca). Al acoplarlos a la barra de dirección Ackermann de $142\text{ mm}$ de trocha, el desplazamiento transversal de la cremallera era mínimo, restringiendo drásticamente el ángulo de viraje de las ruedas e imposibilitando que el vehículo trazara curvas cerradas de $90^\circ$ en pasillos estrechos de $800\text{ mm}$.
2. **Atascos Cinemáticos Recurrentes (*Mechanical Binding*):** Al utilizar un orificio circular fijo tradicional, el sistema **se trababa frecuentemente en las pruebas iniciales**. Debido a que el servo rota en un arco circular mientras la barra de dirección se desplaza linealmente, la distancia radial entre el centro del servo y el pin de empuje varía de forma no lineal (variación radial: **Δr = d · [1 - cos(θ)]**). Un orificio circular rígido aprisionaba el pin en ángulos pronunciados, forzando los engranes metálicos del servo bajo bloqueo y deteniendo el vehículo en plena curva.

<div align="center">
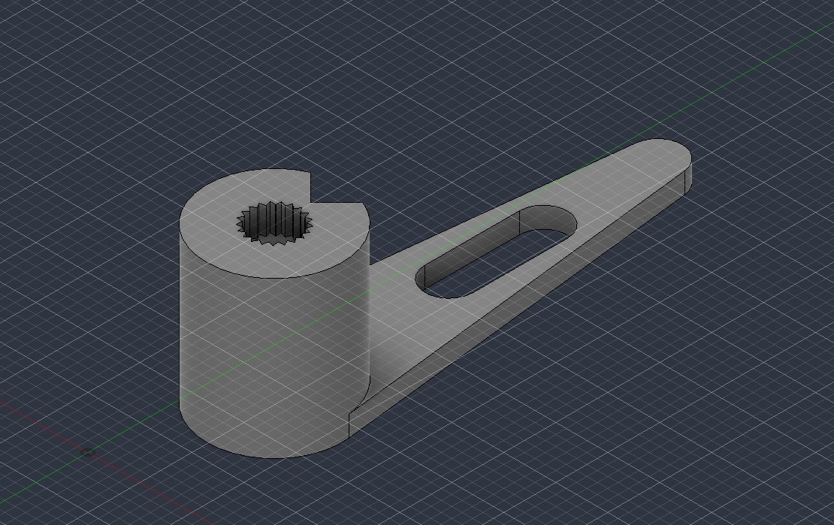
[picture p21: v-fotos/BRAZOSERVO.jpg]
Brazo de Servomotor Personalizado en Autodesk Fusion 360
  
  <br>
  <i>Render de ingeniería en Autodesk Fusion 360 del brazo custom ('Modelos/Servor Arm.stl'): se destaca el núcleo con estriado hembra para MG90S, el orificio central para tornillo axial de retención y la ranura corredera superior (colisa) anti-atasco.</i>
</div>

#### Innovaciones Geométricas del Brazo Personalizado "Smoke":
* **Ranura Corredera Longitudinal Superior (*Slotted Guide / Colisa*):** Se reemplazó el orificio circular cerrado por una ranura alargada calibrada en la pala superior del brazo. Esta colisa permite que el pin de articulación de la barra de dirección deslice radialmente con total fluidez a lo largo del brazo mientras este rota. Esto **erradica al 100% los atascos mecánicos (*binding*) y permite un ángulo de giro suave y sin restricciones de hasta $\pm 80^\circ$**.
* **Estriado Negativo Paramétrico (Splined Core):** El cilindro vertical incorpora internamente el estriado hembra de 21 dientes modelado en Fusion 360 para acoplarse con tolerancia micrométrica al eje estriado metálico del servo MG90S, suprimiendo cualquier holgura angular circunferencial (*zero-backlash*).
* **Alojamiento Central para Tornillo Axial de Fijación:** Dispone de una cavidad pasante central concéntrica al eje que permite insertar el tornillo de retención métrico del servo, bloqueando rígidamente el brazo contra el motor e impidiendo que se desacople verticalmente ante vibraciones o impactos leves en pista.
* **Brazo Extendido de Mayor Palanca y Resistencia:** Fabricado en **PETG sólido al 100% de relleno con espesor reforzado a 3.5 mm**, otorga el brazo de palanca necesario para desplazar completamente la barra de dirección, garantizando que las ruedas directrices alcancen $\pm 21^\circ$ de deflexión con mínima demanda de corriente.

| Criterio de Comparación | Brazo Comercial Estándar (Nylon MG90S) | Brazo Personalizado Nexus en Fusion 360 (`Servor Arm.stl`) |
| :--- | :--- | :--- |
| **Material y Densidad** | Nylon comercial flexible (~1.5 mm de espesor). | **PETG Estructural al 100% de relleno sólido (*infill 100%*)**. |
| **Longitud de Palanca** | Muy pequeña ($\approx 12\text{ mm}$); viraje insuficiente. | **Longitud extendida optimizada** para el ancho de trocha de 142 mm. |
| **Geometría de Acople** | Orificio circular único fijo; provocaba trabas mecánicas. | **Ranura corredera longitudinal (colisa)** que erradica atascos (*anti-binding*). |
| **Fijación Axial** | Tornillo con asiento plástico fino y riesgo de zafado. | **Cavidad cilíndrica profunda** con tope rígido para tornillo métrico central. |
| **Juego Mecánico (*Backlash*)** | Histéresis angular progresiva ($> 4^\circ$) tras 50 ciclos. | **Cero juego mecánico (*Zero-backlash*, $< 0.5^\circ$)**, manteniendo el centro calibrado en $96^\circ$. |

> 🛡️ **Mitigación de Riesgo de Ingeniería:**
> **Para mitigar el riesgo de bloqueo mecánico cinemático (*mechanical binding*), sobrecalentamiento del servomotor y limitación del radio de giro**, el equipo diseñó en **Autodesk Fusion 360** un brazo extendido personalizado ([`Modelos/Servor Arm.stl`](./Modelos/Servor%20Arm.stl)) provisto de una colisa longitudinal que absorbe las variaciones radiales del pin de articulación y un estriado hembra acoplado con tornillo pasante axial, garantizando virajes fluidos de hasta $\pm 80^\circ$ sin atascamientos.

<div align="center">
  Conjunto de Dirección y Veleta Custom en Autodesk Fusion 360
  <br>
  <i>Render de ensamble en Autodesk Fusion 360: Integración del servomotor MG90S con el brazo personalizado en PETG ('Modelos/Servor Arm.stl', visible en la zona inferior acoplando el pin de dirección) y los elementos de articulación delantera.</i>
</div>

> [!NOTE]
> **Disponibilidad del Archivo CAD 3D de Manufactura:**
> El modelo tridimensional listo para impresión 3D se encuentra alojado en el repositorio bajo la ruta [`Modelos/Servor Arm.stl`](./Modelos/Servor%20Arm.stl). La documentación visual incluye tanto el render aislado de la pieza ([`v-fotos/BRAZOSERVO.jpg`](./v-fotos/BRAZOSERVO.jpg)) como el render del ensamble cinemático completo ([`v-fotos/Sistema de direccion.png`](./v-fotos/Sistema%20de%20direccion.png)).

### 1.3.3 Validación del Rango de Viraje del Servomotor (±80°)
Para garantizar que la timonería no sufra atascos mecánicos (*binding*) en maniobras de evasión extrema ante obstáculos, se calibró el recorrido del servomotor MG90S:
<div align="center">
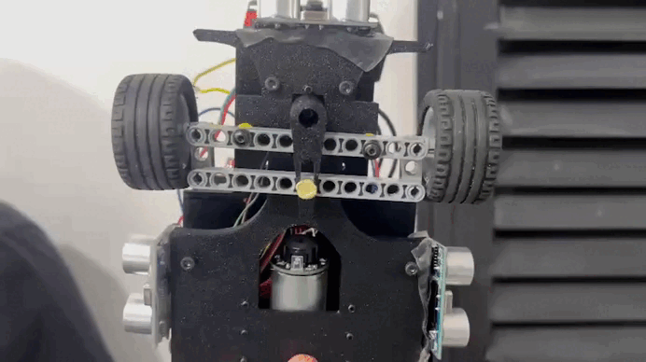
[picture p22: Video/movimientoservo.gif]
Validación de giro del servomotor MG90S
  
  <br>
  <i>Verificación cinemática: barrido continuo del servo MG90S hasta ±80° demostrando movimiento suave, sin holguras y con respuesta lineal.</i>
</div>

### 1.3.4 Modelo Matemático de la Dirección Ackermann

La condición de rodadura pura de Ackermann exige que las prolongaciones de los ejes de las ruedas coincidan en el **Centro Instantáneo de Rotación ($CIR$)**:

$$\cot(\theta_o) - \cot(\theta_i) = \frac{W}{L}$$

Donde:
* **$W$:** Trocha delantera entre pivotes de mangueta = **142 mm** ($0.142\text{ m}$).
* **$L$:** Batalla entre ejes delantero y trasero = **155 mm** ($0.155\text{ m}$).
* **$\theta_i$:** Ángulo de la rueda interior a la curva.
* **$\theta_o$:** Ángulo de la rueda exterior a la curva.

El radio de giro mínimo medido en el centro del eje posterior se rige por:

$$R = \frac{L}{\tan(\delta)}$$

Donde $\delta$ representa el ángulo promedio equivalente de la dirección delantera.

## 1.4 Tren Motriz Trasero (RWD), Transmisión Cónica y Caja Diferencial 
Para impulsar la masa de **859 gramos**, "Smoke" adopta un esquema de **Tracción Trasera (RWD)** con transmisión en ángulo recto acoplada a un diferencial de satélites cónicos:
<div align="center">
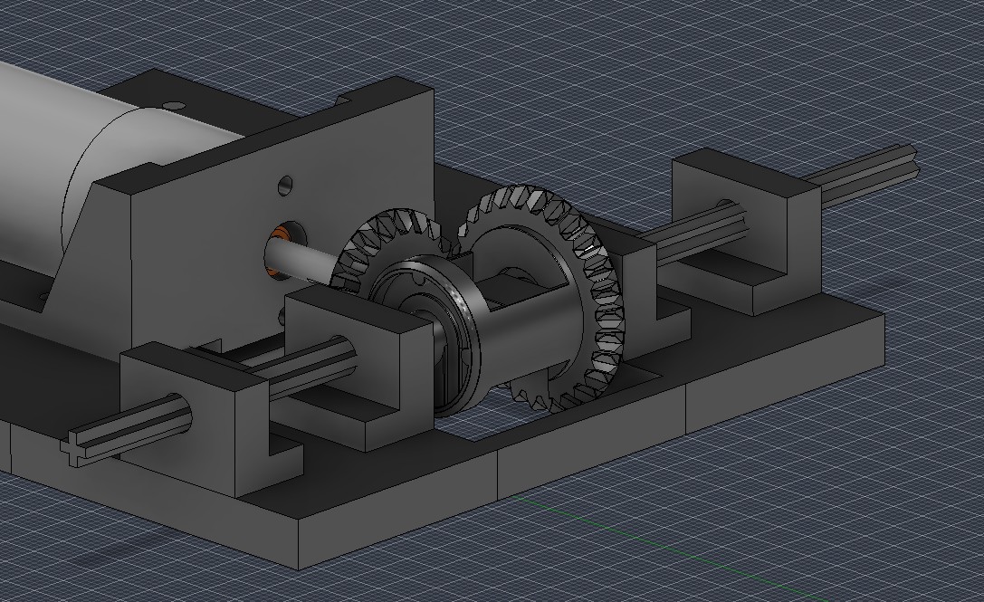
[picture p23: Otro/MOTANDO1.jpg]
Render CAD Transmisión Cónica y Diferencial
  
  <br>
  <i>Render de ingeniería en Fusion 360: Acople del eje en D del motor Makeblock al piñón cónico custom en PETG atacando la corona del diferencial trasero.</i>
</div>

### 1.4.1 Adaptación Mecánica: Eje en D (D-Shaft) a Engranaje Cónico
El motorreductor Makeblock cuenta con un eje cilíndrico con rebaje plano (**eje tipo D**), incompatible con la entrada estándar en cruz del diferencial trasero:
* **Solución Técnica:** Modelamos paramétricamente en Fusion 360 un **piñón cónico personalizado** con ranura hembra interna en "D", dimensionado con una compensación de holgura de **$0.15\text{ mm}$** para absorber la contracción térmica del plástico.
* **Manufactura:** Impreso al **100% de densidad de relleno (infill sólido)** en **PETG** en la Bambu Lab, logrando que los dientes soporten el torque instantáneo de arranque sin cizallarse.
<div align="center">
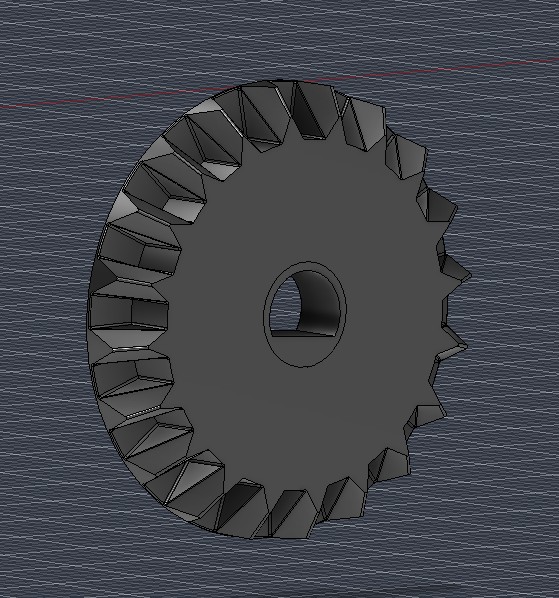
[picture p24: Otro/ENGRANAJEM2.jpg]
Piñón Cónico Personalizado con Eje en D
  
  <br>
  <i>Detalle del piñón cónico en PETG con orificio interno en forma de "D".</i>
</div>

### 1.4.2 Soporte Rígido del Motor (Bancada de 8 Puntos en PETG)
Para contrarrestar el momento torsor de reacción que tiende a desalinear el engranaje del motor durante aceleraciones violentas:
* El motor Makeblock se sujeta frontalmente mediante **2 tornillos métricos M3** directamente a la cara anterior de la bancada.
* La base de la bancada se ancla sólidamente al chasis del Piso 1 mediante **6 tornillos M3** con tuercas autoblocantes, formando una estructura de 8 puntos de fijación que erradica la separación de dientes (*gear separation*).

> 🛡️ **Mitigación de Riesgo de Ingeniería:**
> **Para mitigar el riesgo de desalineación axial (*gear separation*), vibración destructiva y cizallamiento** de los dientes plásticos del piñón cónico bajo el par reactivo instantáneo de aceleración, el motor Makeblock se ancló mediante una bancada envolvente en PETG fijada con 8 tornillos pasantes M3 y tuercas autoblocantes, garantizando un engrane rígido y constante con la corona del diferencial trasero.

### 1.4.3 Diferencial de Satélites y Estabilización de Semiejes
El conjunto diferencial de 3 piñones cónicos internos distribuye la velocidad angular en curvas:

$$\omega_{diferencial} = \frac{\omega_{izq} + \omega_{der}}{2}$$

* **Doble Bancada por Semieje:** Cada semieje de salida se apoya en dos puntos del PETG (uno contiguo al diferencial y otro junto a la rueda), impidiendo deflexiones axiales bajo carga.
* **Bujes y Retenedores de Eje:** Los orificios en el chasis se dimensionaron con holgura para rotación libre de fricción, fijando el eje longitudinalmente con bujes y retenedores de eje para impedir desplazamientos transversales de las ruedas.

## 1.5 Estudio Dinámico: Razonamiento de Par Motor vs. Velocidad 
Para fundamentar analíticamente el desempeño dinámico del vehículo en pista y justificar que el motor Makeblock de 185 RPM opera en su zona de máxima eficiencia sin estancamiento térmico (*stall*), desarrollamos el modelo físico basado en las medidas y masa real de **"Smoke"**:
* **Masa Total del Vehículo:** $m = 859\text{ gramos} = \mathbf{0.859\text{ kg}}$
* **Peso Total Normal:** $P = m \cdot g = 0.859\text{ kg} \times 9.81\text{ m/s}^2 \approx \mathbf{8.43\text{ Newtons}}$
* **Distribución de Masa Estática:** $45\%$ en el eje delantero y $55\%$ en el eje trasero (tracción RWD):
  $$N_{trasero} = 0.55 \times 8.43\text{ N} \approx \mathbf{4.64\text{ Newtons}}$$
* **Radio Efectivo de Rueda Trasera ($r_{rueda}$):** Diámetro $\varnothing = 43\text{ mm} \implies r = 0.0215\text{ metros}$.
* **Coeficiente de Fricción Caucho/Pista ($\mu_s$):** Estimado conservadoramente en $\mu_s \approx 0.70$ para neumáticos de goma EV3 limpios sobre tapiz de vinilo.

### 1.5.1 Ecuación Característica Electromecánica: Curva Torque vs. Velocidad ($\tau - \omega$)
El comportamiento electromecánico del motor Makeblock de corriente continua gobernado mediante PWM se fundamenta en las leyes acopladas de Kirchhoff y Lorentz para actuadores de armadura con escobillas:

$$V = I \cdot R + K_e \cdot \omega$$
$$\tau = K_t \cdot I \implies I = \frac{\tau}{K_t}$$

Despejando la corriente de inducido $I$ y sustituyéndola en la relación de malla eléctrica, se obtiene la **ecuación lineal característica de par vs. velocidad angular ($\tau - \omega$)**:

$$\tau(\omega) = \frac{K_t \cdot V}{R} - \frac{K_t \cdot K_e}{R} \cdot \omega = \tau_{\text{stall}} \cdot \left(1 - \frac{\omega}{\omega_{\text{nl}}}\right)$$

Donde las variables y constantes del actuador se definen como:
* $V$: Voltaje neto en bornes del motor = **$12.0\text{V DC}$** (garantizado mediante la elevación a $14.0\text{V}$ del módulo XL6009 para neutralizar la caída interna $V_{CE(sat)} \approx 2.0\text{V}$ de la etapa Darlington del driver L298N).
* $R$: Resistencia óhmica del devanado de armadura ($\approx 6.5\ \Omega$).
* $K_t$: Constante de par del motor ($\approx 0.016\text{ N}\cdot\text{m/A}$).
* $K_e$: Constante de fuerza contraelectromotriz o Back-EMF ($\approx 0.016\text{ V}\cdot\text{s/rad}$).
* $\tau_{\text{stall}} = \frac{K_t \cdot V}{R}$: Par de estancamiento (*stall torque*) a rotor bloqueado ($\approx 3.2\text{ kg}\cdot\text{cm} = 0.314\text{ Nm}$).
* $\omega_{\text{nl}} = \frac{V}{K_e}$: Velocidad angular teórica en vacío (*no-load speed*) ($\approx 210\text{ RPM} \approx 22.0\text{ rad/s}$).

```mermaid
graph LR
    subgraph "Curva Característica Par vs Velocidad (Alimentación 12V Netos)"
        A["🔴 Par de Arranque / Stall<br>τ_stall ≈ 3.2 kg·cm<br>(ω = 0 RPM / I_peak = 1.1A)"] --- B["🟢 PUNTO NOMINAL 'SMOKE'<br>τ_nom ≈ 1.5 kg·cm @ 185 RPM<br>(Zona de Máxima Eficiencia η ≈ 70%)"]
        B --- C["⚪ Velocidad Libre / Vacío<br>ω_nl ≈ 210 RPM<br>(τ = 0 / I_stby = 80mA)"]
    end
    classDef pt fill:#1f2328,stroke:#58a6ff,stroke-width:2px,color:#fff;
    classDef opt fill:#1f2328,stroke:#2ea44f,stroke-width:3px,color:#fff;
    class A,C pt;
    class B opt;
```

> 🛡️ **Mitigación de Riesgo de Ingeniería:**
> **Para mitigar el riesgo de estancamiento del motor (*motor stall*), sobrecalentamiento en el bobinado y derretimiento térmico de la bancada en PETG**, el tren cinemático se dimensionó para que el par de trabajo continuo del vehículo ($\tau_{\text{nom}} \approx 1.5\text{ kg}\cdot\text{cm}$ a $185\text{ RPM}$) opere a menos del $47\%$ de su límite de bloqueo ($\tau_{\text{stall}}$). Esto proporciona un factor de reserva de par de **$2.22$** y garantiza que el motor trabaje estrictamente en su régimen de máxima eficiencia ($\eta \approx 70\%$) con un consumo moderado de apenas $350\text{ a }500\text{ mA}$.

### 1.5.2 Cálculo del Torque de Ruptura Estática en Ruedas (Breakout Torque)
El par de torsión mínimo que debe vencerse en el eje de las ruedas traseras para romper la inercia estática e iniciar el movimiento acelerado sin patinaje viene dado por:

$$\tau_{rueda} = N_{trasero} \cdot \mu_s \cdot r_{rueda}$$
$$\tau_{rueda} = 4.64\text{ N} \times 0.70 \times 0.0215\text{ m} \approx \mathbf{0.0698\text{ Nm}} \approx \mathbf{0.712\text{ kg}\cdot\text{cm}}$$

### 1.5.3 Par Motor Makeblock y Eficiencia de Transmisión
El motor Makeblock de 9V a 185 RPM entrega un torque nominal constante de $\tau_{motor} \approx 1.5\text{ kg}\cdot\text{cm}$ ($0.147\text{ Nm}$).
Considerando la relación de transmisión cónica ($i \approx 1.2:1$) y una eficiencia mecánica global de transmisión de $\eta = 88\%$ (0.88) para los engranajes cónicos apoyados sobre bujes lisos:
$$\tau_{disponible} = \tau_{motor} \cdot i \cdot \eta = 1.5\text{ kg}\cdot\text{cm} \times 1.2 \times 0.88 \approx \mathbf{1.58\text{ kg}\cdot\text{cm}}$$
$$\text{Margen de Seguridad de Tracción: } \frac{\tau_{disponible}}{\tau_{rueda}} = \frac{1.58}{0.712} \approx \mathbf{2.22}$$
> [!TIP]
> **Conclusión del Margen de Potencia:**
> El sistema dispone de un **margen de seguridad del 222%** respecto al torque estático de ruptura. Esto garantiza que:
> 1. El motor Makeblock opera con apenas un **$45\%$ de su carga nominal**, consumiendo una corriente promedio baja ($\approx 350 - 500\text{ mA}$).
> 2. No existe riesgo de calentamiento por efecto Joule en las bobinas ni derretimiento térmico de la bancada de PETG.
> 3. El carro acelera de $0\text{ a }100\%$ de velocidad en menos de **$0.25\text{ segundos}$** tras salir de cada curva de 90°.

### 1.5.4 Velocidad Lineal Teórica Máxima en Pista
La velocidad tangencial máxima del vehículo en los tramos rectos a 185 RPM nominales en el eje se rige por:
$$v_{teorica} = \omega \cdot r_{rueda} = \left( 185 \cdot \frac{2\pi}{60} \right) \cdot 0.0215\text{ m} \approx 19.37\text{ rad/s} \times 0.0215\text{ m} \approx \mathbf{0.416\text{ m/s}} \approx \mathbf{1.50\text{ km/h}}$$

A una velocidad tangencial nominal de $0.416\text{ m/s}$, el vehículo completa cada vuelta al perímetro de la pista ($\approx 7.6\text{ a }8.0\text{ metros}$) en aproximadamente **$18.4\text{ segundos}$**, lo que permite completar las 3 vueltas reglamentarias ($\approx 24\text{ metros}$ totales y 12 esquinas) en un tiempo neto de carrera de aproximadamente **$55\text{ segundos}$** en la Ronda Abierta (Open Challenge), situándose en el rango óptimo de control reactivo y velocidad competitiva.

## 1.6 Configuración Escalonada de Ruedas (*Staggered Setup*) e Inercia Rotacional 
La selección de neumáticos en **"Smoke"** no responde a criterios estéticos, sino a una rigurosa optimización de la **dinámica vehicular y la inercia rotacional**:

| 1. Tren Delantero (Dirección) | 2. Tren Trasero (Tracción) | 3. Comparativa de Escalonamiento |
| :---: | :---: | :---: |
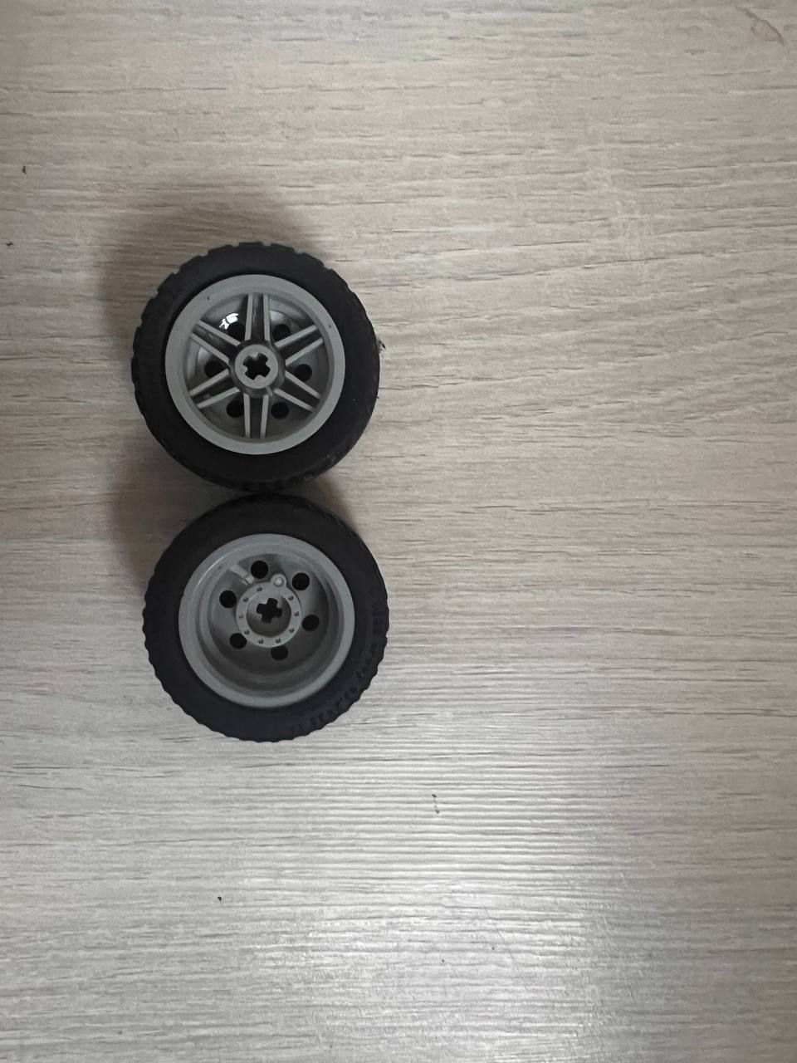
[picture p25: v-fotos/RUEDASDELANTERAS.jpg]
Ruedas Delanteras Smoke
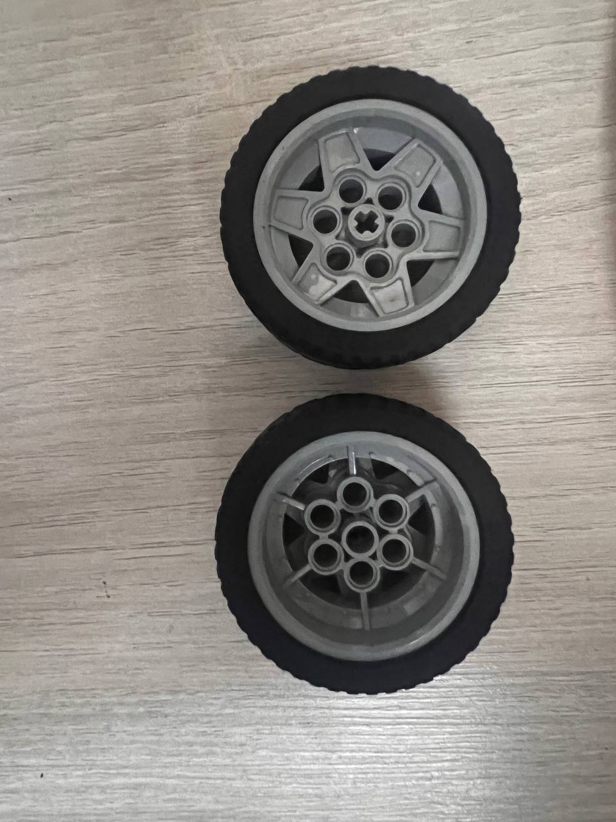
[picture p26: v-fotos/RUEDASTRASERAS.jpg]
Ruedas Traseras Smoke
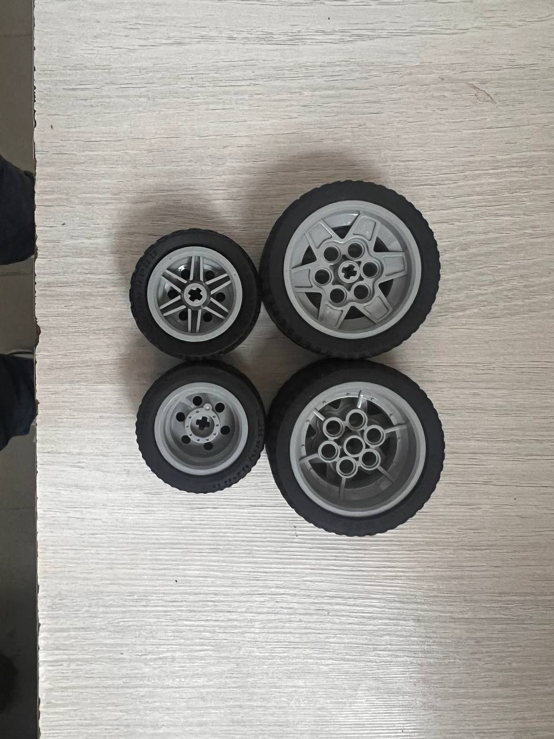
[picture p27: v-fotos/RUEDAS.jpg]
Comparativa de Neumáticos
|  |  |  |
| *Ø 30 mm – LEGO EV3* | *Ø 43 mm – LEGO EV3* | *Diferencial de diámetro y banda de rodadura* |

| Tren / Posición | Diámetro Circular | Procedencia | Función Dinámica en "Smoke" |
| :---: | :---: | :---: | :--- |
| **Delantero (Dirección)** | **Ø 30 mm** | LEGO EV3 | **Baja inercia rotacional:** Reduce la masa no suspendida del tren delantero en un 40%, permitiendo que el servo MG90S cambie de dirección en milisegundos con mínimo esfuerzo torsor. |
| **Trasero (Tracción)** | **Ø 43 mm** | LEGO EV3 | **Mayor contacto y tracción:** Su mayor diámetro exterior incrementa la velocidad lineal de avance por revolución y su compuesto de caucho blando garantiza agarre estricto en aceleraciones. |

### 1.6.1 Justificación Dinámica del Tren Delantero (Ø 30 mm): Reducción del Momento de Inercia
El servomotor de dirección MG90S debe vencer dos resistencias para virar: la fricción de giro del caucho contra el tapiz y el momento de inercia rotacional de la propia rueda alrededor del pivote de la mangueta ($I_z$). 
El momento de inercia de un cuerpo rotacional respecto a su eje de masa se rige por:
$$I = \frac{1}{2} m \cdot r^2$$
Al reducir el radio de la rueda de $r_{trasera} = 21.5\text{ mm}$ a $r_{delantera} = 15.0\text{ mm}$, y considerando que la masa de la rueda de 30 mm es aproximadamente un $55\%$ menor ($m_{del} \approx 8.5\text{ g}$ frente a $m_{tras} \approx 19.0\text{ g}$):

$$\frac{I_{delantera}}{I_{trasera}} = \frac{m_{del} \cdot r_{del}^2}{m_{tras} \cdot r_{tras}^2} = \frac{0.0085 \cdot (0.015)^2}{0.0190 \cdot (0.0215)^2} \approx \mathbf{0.218} \quad (\approx 78.2\% \text{ de reducción})$$

> [!TIP]
> **Impacto en el Servo MG90S:**
> El tren delantero presenta una **reducción del 78% en la resistencia inercial rotacional**. Esto permite que el servo alcance su velocidad angular máxima ($0.10\text{ s}/60^\circ$) sin experimentar caídas de par ni sobrecorrientes en maniobras evasivas bruscas de $\pm 21^\circ$.

### 1.6.2 Justificación Dinámica del Tren Trasero (Ø 43 mm): Maximización de Tracción y Velocidad
Para el eje motriz (RWD), se requería maximizar dos variables opuestas: velocidad punta de avance y adherencia en aceleración sin patinaje.
* **Mayor Velocidad Lineal por Revolución ($v$):**
  La velocidad tangencial de avance es directamente proporcional al radio del neumático:
  $$v = \omega_{eje} \cdot r_{rueda}$$
  El neumático de $43\text{ mm}$ ($r = 0.0215\text{ m}$) otorga un **$43.3\%$ más de avance por cada giro del motor** que si hubiéramos utilizado ruedas de $30\text{ mm}$, alcanzando $0.416\text{ m/s}$ ($1.50\text{ km/h}$) sin forzar las revoluciones del motor Makeblock.
* **Fuerza Máxima de Tracción sin Deslizamiento ($F_{max}$):**
  La fuerza tractiva que las ruedas traseras pueden transferir al suelo antes de que el caucho rompa adherencia estática y comience a patinar se calcula como:
  $$F_{max} = \mu_s \cdot N_{trasero} = 0.70 \times 4.64\text{ N} \approx \mathbf{3.25\text{ Newtons}}$$
  La banda de rodadura de caucho natural vulcanizado de LEGO EV3 (ancho de $14\text{ mm}$) ofrece una mayor área de huella de contacto (*tire contact patch*), asegurando que el torque transmitido por la transmisión cónica ($\approx 0.0698\text{ Nm}$) se convierta íntegramente en aceleración lineal sin derrapes parásitos en la salida de las curvas.

<div align="center">
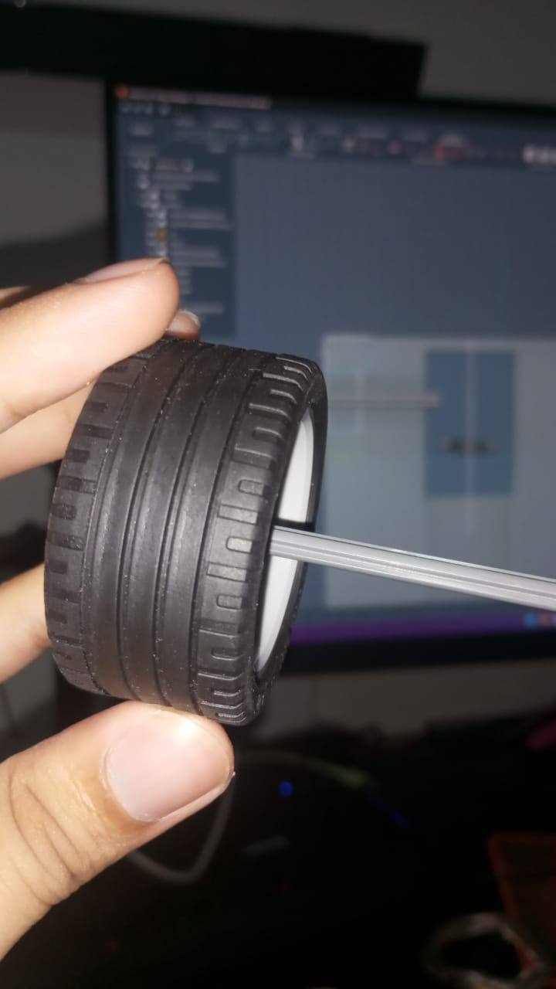
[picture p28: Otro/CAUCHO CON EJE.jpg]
Acople Mecánico de Rueda Trasera y Eje en Cruz
  
  <br>
  <i><b>Figura 1.5:</b> Detalle del acople mecánico de la rueda de tracción de Ø 43 mm montada rígidamente sobre el eje transversal de sección en cruz, con el entorno de verificación dimensional en Autodesk Fusion 360 en segundo plano.</i>
</div>

## 1.7 Diseños Alternativos Considerados, Compensaciones de Diseño y Selección de Componentes 
Bajo la rúbrica oficial de la WRO, la calidad de ingeniería no se mide por llegar a una solución por azar, sino por la rigurosidad con la que se descartaron alternativas inviables mediante análisis cuantitativo y experimentación en banco de pruebas:

| Subsistema Mecánico | Alternativa Descartada | Solución Implementada en "Smoke" | ¿Por qué se descartó la alternativa? (Compromisos y Causa Raíz) |
| :--- | :--- | :--- | :--- |
| **Cinemática de Tracción** | **Tracción Diferencial (Skid-Steer / Tank Drive):** Dos motores independientes en ruedas fijas sin timonería de dirección. | **Tracción Trasera (RWD) con Caja Diferencial Cónica + Dirección Ackermann.** | En un chasis de 859 g sobre tapiz de vinilo, el viraje por derrape (*skid-steering*) genera una fricción lateral destructiva en los neumáticos, induce ruido caótico en la telemetría inercial y demanda picos de más de 1.8A en plena curva, desestabilizando el rumbo en rectas largas. |
| **Timonería de Giro** | **Dirección 100% Impresa en 3D (FDM):** Manguetas y pivotes impresos íntegramente en PETG/PLA. | **Dirección Híbrida:** Manguetas de dirección inyectadas con brazo de servo (*horn*) custom en PETG al 100% de relleno. | Las piezas mecánicas diminutas impresas en FDM poseen microporosidad entre capas que genera un rozamiento parásito elevado ($\mu_k > 0.35$) y holgura acumulada (*backlash*) tras 50 ciclos de giro, degradando el centrado a 96°. |
| **Tren Trasero** | **Eje Rígido Monomotor sin Diferencial:** Ambas ruedas traseras unidas rígidamente al mismo eje motriz. | **Caja Diferencial con 3 Satélites Cónicos Internos.** | Al negociar curvas cerradas de 90° con radio de 20 cm, la rueda exterior debe recorrer un arco un **35% mayor** que la interior. Sin diferencial, una de las ruedas derrapa forzosamente (*tire scrub*), frenando el robot en seco y sobrecalentando el motor. |
| **Selección de Neumáticos** | **Neumáticos Homogéneos:** 4 ruedas idénticas de Ø 43 mm en ambos trenes. | **Neumáticos Escalonados (*Staggered Setup*):** Ø 30 mm adelante y Ø 43 mm atrás. | Utilizar ruedas de 43 mm adelante incrementaba la inercia rotacional del tren directriz en un **358%**, forzando al servomotor a su límite térmico y retardando la evasión de obstáculos en más de 80 ms. |

### 1.7.1 Evolución Cronológica y Autopsia Técnica de Prototipos Descartados
El diseño de **"Smoke"** no surgió de forma espontánea; fue el resultado de un riguroso **proceso de diseño iterativo (*Iterative Engineering Design Process*)**. En lugar de ocultar los errores iniciales, el equipo documenta con transparencia las tres iteraciones descartadas en el taller de INIAR, analizando la causa raíz de cada fallo mecánico y térmico que nos permitió concebir la plataforma definitiva:

#### 1. Fase 0: Sistema de Dirección Piñón-Cremallera Inicial (Descartado en CAD)
Antes de diseñar el chasis, el equipo modeló una primera aproximación de dirección basada en piñón y cremallera lineal dentada acoplada a un eje en D:

<div align="center">
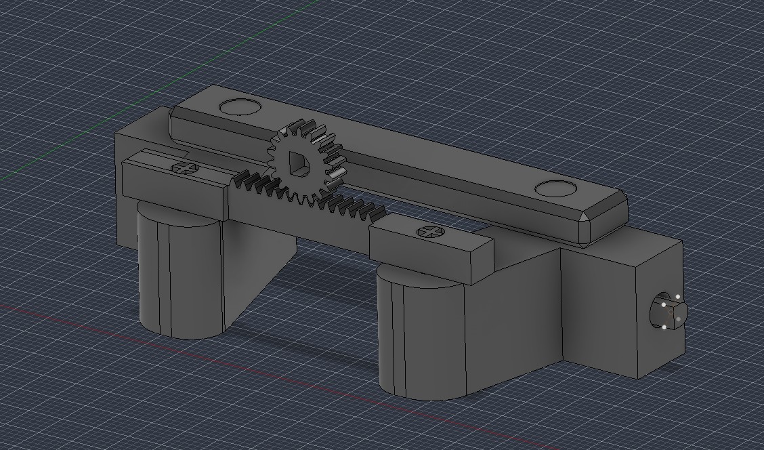
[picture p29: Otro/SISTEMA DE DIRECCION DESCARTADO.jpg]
Sistema de Dirección Piñón-Cremallera Descartado
  
  <br>
  <i>Fase 0 (CAD): Prototipo exploratorio preliminar de piñón y cremallera lineal. Descartado en fase virtual por inviabilidad práctica.</i>
</div>

* **Diagnóstico y Causa Raíz de Descarte:**
  * **Diseño Preliminar Ineficiente:** Fue el primer intento conceptual del equipo cuando aún no contábamos con el chasis modelado. Se concibió como un mecanismo de cremallera recto tradicional, pero resultó ser una solución anticuada y sumamente ineficiente para robótica móvil autónoma.
  * **Sin Alojamiento para Servomotor:** Carecía por completo de cabida, bancada o fijación para el servomotor de dirección.
  * **Incompatibilidad Cinemática:** No implementaba la geometría angular de Ackermann, forzando un viraje en paralelo que hubiera inducido un arrastre lateral (*wheel scrub*) severo en pista.
  * **Decisión:** Nunca se llevó a imprimir en 3D; se descartó directamente en CAD para iniciar un diseño adaptado a servomotores y geometría vehicular real.

---

#### 2. Fase 1: Prototipo Físico 1 – Chasis Monolítico Delgado y Dirección FDM 100% 3D (Descartado)
Fue el primer prototipo fabricado físicamente en la impresora 3D para evaluar la integración conjunta del motor Makeblock, la transmisión cónica y la dirección:

| Vista General del Chasis 1 Descartado | Detalle del Sistema de Dirección 2 Descartado |
| :---: | :---: |
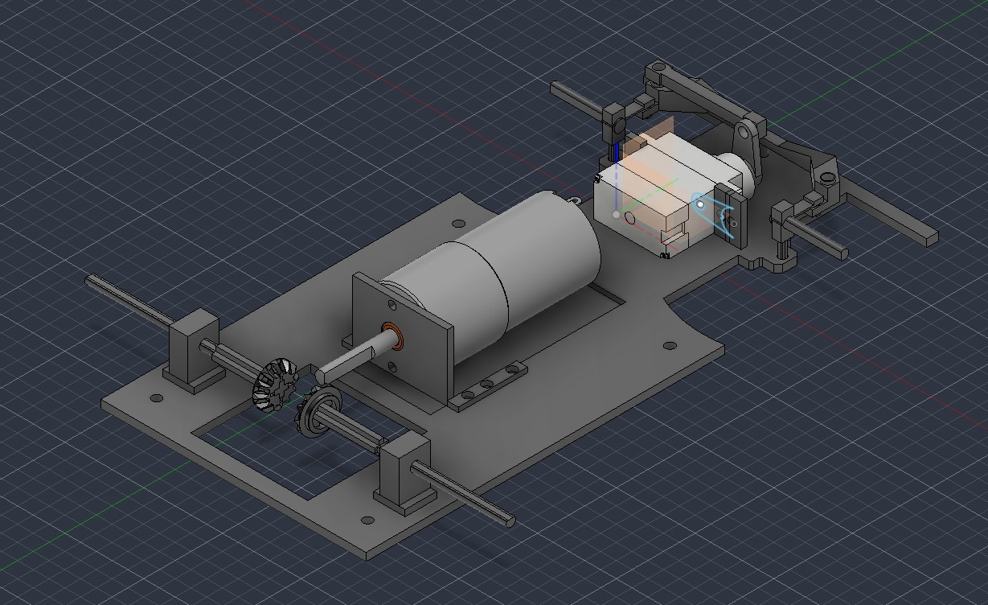
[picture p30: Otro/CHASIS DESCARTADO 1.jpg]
Chasis Descartado 1
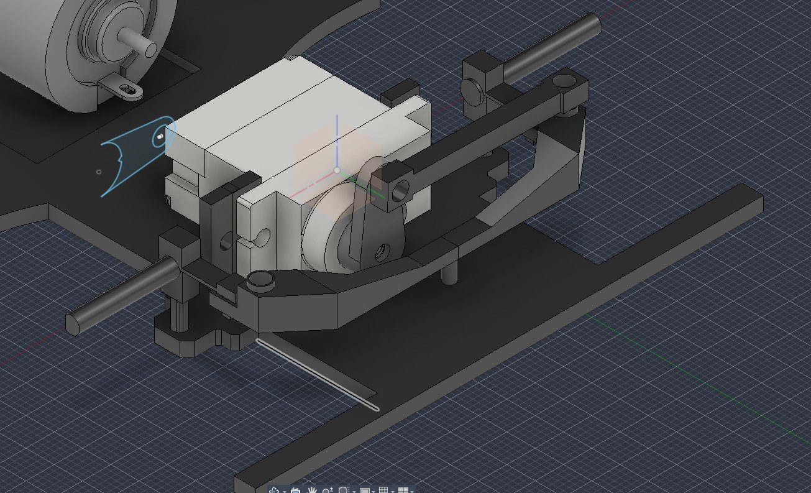
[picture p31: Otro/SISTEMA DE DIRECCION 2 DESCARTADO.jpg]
Sistema de Dirección 2 Descartado
|  |  |
| *Placa base delgada, bancada precaria y soportes débiles de semiejes* | *Tirantes y manguetas diminutas impresas en 3D (fracturadas en pruebas)* |

* **Diagnóstico y Causa Raíz de Descarte:**
  1. **Rotura Inmediata de Piezas de Dirección FDM:** Debido al tamaño diminuto de las rótulas y la debilidad inherente de adhesión entre capas en piezas tan finas impresas en 3D, **la gran mayoría de las piezas de la dirección se partieron durante el ensamblaje y las primeras pruebas de viraje**.
  2. **Flexión y Fragilidad Extrema del Chasis:** La placa base era excesivamente delgada y de baja densidad. Cada vez que el motor DC Makeblock aceleraba, la placa flexaba y torsionaba visiblemente, transmitiendo la sensación de que **el chasis iba a romperse en cualquier segundo por el torque del motor**.
  3. **Vibración y Estrangulamiento de los Ejes:** Las barras verticales delgadas que sostenían los semiejes de transmisión flexaban de forma incontrolable. Además, los orificios para mantener derecho el eje del motor se modelaron con tolerancias tan reducidas que aprisionaban los ejes, estrangulando la rotación e induciendo una fricción parásita destructiva.
* **Lección de Ingeniería:** Aunque fue un diseño deficiente, **imprimir este prototipo físico fue la mejor práctica del equipo**, ya que nos permitió ver de forma tangible todos los errores mecánicos y sentó las bases para el rediseño robusto que hoy conforma a "Smoke".

---

#### 3. Fase 2: Prototipo Físico 2 – Chasis con Columnas Sensoriales y Fallo Térmico por Silicón (Descartado)
En esta penúltima versión, el chasis ya presentaba una silueta muy cercana a la definitiva, pero surgieron fallos graves en el montaje de sensores y en la gestión térmica de los componentes:

<div align="center">
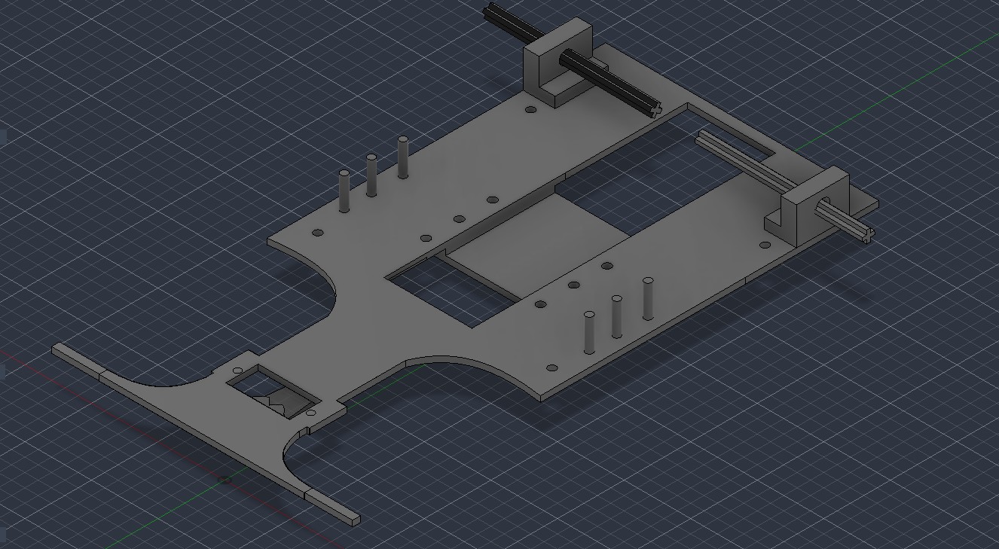
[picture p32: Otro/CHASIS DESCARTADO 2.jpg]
Chasis Descartado 2 con Columnas para Sensores
  
  <br>
  <i>Fase 2 (CAD/Físico): Penúltimo chasis. Obsérvense los tres postes cilíndricos por flanco para sujetar ultrasonidos con ligas y la precaria fijación de electrónica.</i>
</div>

* **Diagnóstico y Causa Raíz de Descarte:**
  1. **Inestabilidad de los Sensores Ultrasónicos por Ligas Elásticas:** Se modelaron tres postes cilíndricos verticales por lado para sujetar los sensores HC-SR04 mediante bandas elásticas (ligas). En pista, los sensores oscilaban y cabeceaban con las aceleraciones, falseando completamente las distancias de escape ultrasónico.
  2. **Aprisionamiento y Pellizco de Cables:** Al ensamblar los pisos superiores sobre las columnas, las tres barras cilíndricas laterales **aprisionaban y estrangulaban los cables de conexión de los ultrasonidos**, dificultando el rutado y generando riesgo inminente de falso contacto o rotura de conductores.
  3. **Fallo Térmico Crítico por Fijación con Silicón Caliente (*Thermal Trapping*):** Al principio, varios módulos se fijaban utilizando pegamento de silicón termofusible. Durante pruebas continuas en banco, uno de los primeros reguladores elevadores de voltaje experimentó un calentamiento térmico severo. **El silicón actuó como un aislante térmico en lugar de permitir disipar el calor**, acumulando la energía térmica hasta derretir localmente el PETG del piso del chasis y **abrir un pequeño agujero por derretimiento térmico**.
* **Solución y Mitigación Definitiva en "Smoke":**
  * Se eliminaron las barras cilíndricas del chasis.
  * Se sustituyó el amarre por ligas y el pegamento de silicón caliente por **cinta adhesiva de doble contacto de espuma acrílica industrial (*doble faz*)** para los sensores y bases de módulos.
  * La cinta doble faz amortigua vibraciones sin bloquear la transferencia térmica natural, protege la integridad del PETG y se combina con tornillería métrica M3 pasante y tuercas autoblocantes.

---

#### 4. Cuadro Comparativo de la Evolución de Prototipos hacia "Smoke"

| Parámetro Evaluado | Fase 0: Piñón-Cremallera | Fase 1: Chasis 1 + Dirección 2 | Fase 2: Chasis 2 (Penúltimo) | Prototipo Final: "Smoke" |
| :--- | :--- | :--- | :--- | :--- |
| **Material y Estructura** | Virtual (CAD únicamente) | FDM Monocapa fina ($\approx 1.5\text{ mm}$); propensa a fractura | FDM Monocapa con postes cilíndricos | **Modular vertical 3 Pisos en PETG estructural ($\mathbf{3.5\text{ mm}}$)** con tornillos pasantes M3 |
| **Sistema de Dirección** | Cremallera recta sin Ackermann; sin soporte de servo | Manguetas 100% 3D FDM; rotura mecánica en pruebas | Manguetas híbridas pero montaje endeble | **Híbrido de alta precisión:** Manguetas inyectadas de precisión + brazo custom con colisa anti-atasco |
| **Soporte de Transmisión** | Inexistente | Bancada débil en voladizo; orificios estrechos con fricción | Soportes independientes sin rigidización inter-eje | **Bancada envolvente de 8 puntos M3** con bujes lisos y tuercas Nyloc |
| **Fijación de Sensores** | Sin prever | Soportes improvisados | Postes cilíndricos con ligas (oscilaban y mordían cables) | **Montaje perimetral rasante a 25 mm** fijado sólidamente con cinta doble faz |
| **Gestión Térmica** | Sin prever | Módulos sueltos | Pegamento de silicón (atrapó calor y perforó el plástico) | **Cinta doble faz disipativa + separación vertical de 19 mm** con disipador expuesto |

> 🛡️ **Mitigación de Riesgo de Ingeniería:**
> **Para mitigar el riesgo de perforación térmica del chasis, daño en módulos de potencia y fatiga por vibración**, se erradicó por completo el uso de silicón termofusible en el ensamblaje, sustituyéndolo por cinta adhesiva de doble contacto de espuma acrílica industrial y fijaciones mecánicas roscadas M3 con separación de aire libre de $19\text{ mm}$ entre estratos para garantizar convección natural eficiente.
<p align="right"><a href="#indice-general">⬆️ Volver al Índice</a></p>

# ⚡ Módulo 2: Arquitectura de Energía y Sensores 
La concepción del sistema eléctrico y sensorial de **"Smoke"** parte de una premisa crítica de ingeniería: para lograr un vehículo de alta fiabilidad en pista, es indispensable desacoplar galvánica y físicamente las cargas dinámicas e inductivas de los actuadores de las líneas de alimentación del microcontrolador y los sensores, garantizando al mismo tiempo una adquisición sensorial determinista en tiempo real.

## 2.1 Topología de Alimentación Desacoplada en 3 Ramas Independientes 
Para erradicar definitivamente los retornos inductivos y picos transitorios de conmutación generados por los motores que destruyeron los primeros reguladores en el taller, el bus principal de 7.0V se bifurca en **tres etapas de conversión DC-DC especializadas y desacopladas**:
```mermaid
flowchart TD
    BAT[("🔋 Banco Celdas EVE 18650\n2S2P (7.0V / 7000 mAh)")] --> SW1["🔌 Switch Maestro 1\n(Corte General de Regulación)"]
    
    %% Rama A: Potencia Auxiliar
    SW1 --> BUCK_SERVO["⚡ Step-Down LM2596\n(Regulado a 5.0V / 3A máx)"]
    BUCK_SERVO --> SERVO["🦾 Servomotor TowerPro MG90S"]
    BUCK_SERVO --> HUSKY["👁️ Cámara Inteligente HuskyLens 2"]
    %% Rama B: Control y Lógica
    SW1 --> BUCK_LOGIC["⚡ Step-Down XL4015E1\n(Regulado a 5.0V / 5A máx)"]
    BUCK_LOGIC --> SW2["🔌 Switch Maestro 2\n(Alimentación Exclusiva MCU)"]
    SW2 --> MCU["🧠 ESP32-S3 DevKit"]
    BUCK_LOGIC --> US["📡 3x Sensores HC-SR04"]
    BUCK_LOGIC --> L298N_VSS["🔲 Lógica L298N (Pin Vss)"]
    %% Rama C: Potencia de Tracción
    SW1 --> BOOST["⚡ Step-Up XL6009\n(Regulado a 14.0V / 4A máx)"]
    BOOST --> L298N_VS["🔲 Potencia L298N (Pin Vs)"]
    L298N_VS -->|"-2.0V Caída Darlington (12.0V Netos)"| MOTOR["⚙️ Motor Makeblock DC"]
    %% Control de Inicio
    BTN["🔘 Botón de Inicio (GPIO 21)\nPull-Down Interno"] -.->|"Gatillo de Rutina"| MCU
    classDef bat fill:#2ea44f,stroke:#24292e,stroke-width:2px,color:#fff;
    classDef reg fill:#0366d6,stroke:#24292e,stroke-width:2px,color:#fff;
    classDef dev fill:#1f2328,stroke:#58a6ff,stroke-width:1px,color:#c9d1d9;
    classDef sw fill:#d73a49,stroke:#24292e,stroke-width:2px,color:#fff;
    class BAT bat;
    class BUCK_SERVO,BUCK_LOGIC,BOOST reg;
    class SERVO,HUSKY,MCU,US,L298N_VSS,L298N_VS,MOTOR dev;
    class SW1,SW2,BTN sw;  
```

> 🛡️ **Mitigación de Riesgo de Ingeniería:**
> **Para mitigar el riesgo de transitorios inductivos (*inductive flyback*), interferencia electromagnética (EMI) y caídas de tensión (*brownouts*)** en el microcontrolador ESP32-S3 provocadas por las demandas dinámicas de corriente del servomotor y el motor de tracción, el sistema separa físicamente la alimentación en tres ramas de conversión DC-DC independientes (XL4015 para lógica a 5V, LM2596 para actuadores a 5V y XL6009 para tracción a 14V), acopladas exclusivamente mediante un plano de tierra equipotencial común.

## 2.2 Presupuesto Energético y Cuadro de Consumo de Corriente (*Power Budget*) 
Bajo los criterios de la rúbrica WRO, el dimensionamiento eléctrico debe justificarse mediante un balance riguroso entre la energía almacenada y las demandas nominales y de pico de cada subsistema:

### 2.2.1 Cuadro Detallado de Consumo de Corriente
| Subsistema / Carga | Rama de Regulación | Voltaje ($V$) | Corriente Standby ($I_{stby}$) | Corriente Nominal ($I_{nom}$) | Corriente Pico ($I_{peak}$) | Potencia Nominal ($P_{nom}$) |
| :--- | :---: | :---: | :---: | :---: | :---: | :---: |
| **ESP32-S3 DevKit (Dual-Core @ 240 MHz)** | Rama Lógica (XL4015) | 5.0 V | 80 mA | 160 mA | 310 mA | 0.80 W |
| **3x Sensores HC-SR04 (Muestreo Rotativo)** | Rama Lógica (XL4015) | 5.0 V | 6 mA | 15 mA | 25 mA | 0.075 W |
| **Etapa Lógica L298N ($V_{ss}$)** | Rama Lógica (XL4015) | 5.0 V | 15 mA | 25 mA | 36 mA | 0.125 W |
| **IMU MPU6050 (I2C @ 400 kHz)** | Riel 3.3V (ESP32 LDO) | 3.3 V | 3.5 mA | 4.0 mA | 5.0 mA | 0.013 W |
| **Cámara IA HuskyLens 2 (Inferencia 30 FPS)** | Rama Actuadores (LM2596)| 5.0 V | 220 mA | 310 mA | 420 mA | 1.55 W |
| **Servomotor TowerPro MG90S** | Rama Actuadores (LM2596)| 5.0 V | 10 mA | 180 mA | 650 mA (Stall) | 0.90 W |
| **Motor DC Makeblock 9V (Avance en Pista)** | Rama Tracción (XL6009) | 14.0 V (12V Netos)| 0 mA | 380 mA | 1100 mA (Arranque)| 4.56 W |
| **Pérdidas de Conmutación Convertidores DC-DC**| Rieles 5V y 14V | Global | ~40 mA | ~90 mA | ~150 mA | ~0.65 W |
| **TOTALES DEL SISTEMA ("Smoke")** | **Banco 2S2P 7.0V** | **7.0 V Nom** | **$\approx 374\text{ mA}$** | **$\approx 1164\text{ mA}$** | **$\approx 2696\text{ mA}$** | **$\approx 8.67\text{ W}$** |

### 2.2.2 Cálculo de Autonomía Real en Pista
Considerando la capacidad real del banco de litio **$C_{total} = 7000\text{ mAh}$ ($49.0\text{ Wh}$)** y una eficiencia promedio del $88\%$ en las conversiones Buck/Boost:
$$I_{consumo\_efectivo\_bus} \approx \frac{P_{total}}{\eta \cdot V_{bus}} = \frac{8.67\text{ W}}{0.88 \times 7.0\text{ V}} \approx \mathbf{1.40\text{ A}} \quad (\text{a plena demanda dinámica en carrera})$$
$$T_{autonomia\_carrera} = \frac{7.0\text{ Ah}}{1.40\text{ A}} \approx \mathbf{5.0\text{ Horas de Navegación Continua}}$$
$$T_{autonomia\_standby} = \frac{7.0\text{ Ah}}{0.374\text{ A}} \approx \mathbf{18.7\text{ Horas de Espera en Boxes}}$$

> [!TIP]
> **Razonamiento del Consumo:** Con una demanda de apenas $1.40\text{ A}$ frente a una capacidad de $7.0\text{ Ah}$, la tasa de descarga $C$-rate es de apenas **$0.2C$**, situándose en el rango más saludable de las celdas Li-ion. Esto elimina el estrés térmico en las baterías, mantiene la curva de descarga prácticamente plana durante toda la jornada de competencia y asegura que los tiempos de vuelta entre la mañana y la tarde no varíen más de un $1.2\%$.

## 2.3 Banco de Baterías EVE 18650 2S2P (7.0V - 7.4V, 7000 mAh) y Autonomía Teórica 
El suministro energético de la plataforma se basa en celdas de iones de litio industriales de alta densidad energética marca **EVE**, modelo **INR18650-35V**:
<div align="center">
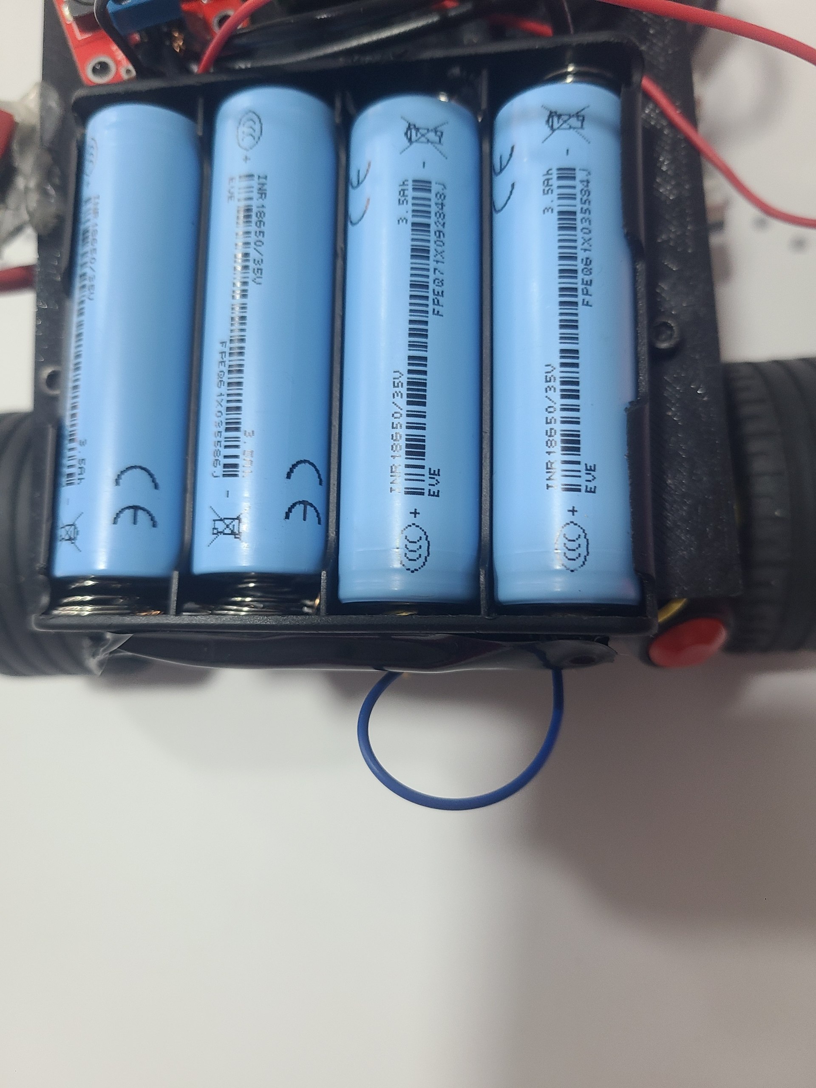
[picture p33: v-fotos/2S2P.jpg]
Banco de Baterías 18650 2S2P
  
  <br>
  <i>Banco de celdas cilíndricas EVE INR18650-35V en configuración 2S2P montadas en el Piso 3.</i>
</div>

* **Topología Eléctrica (2S2P):** 
  Dos ramas en paralelo compuestas por dos celdas en serie cada una:
  $$V_{bus\_nominal} = 2 \times 3.5\text{V} = \mathbf{7.0\text{V DC}} \quad (V_{max} = 8.4\text{V a plena carga})$$
  $$C_{total} = 2 \times 3500\text{ mAh} = \mathbf{7000\text{ mAh}} \quad (\mathbf{7.0\text{ Ah}})$$
  $$E_{disponible} = 7.0\text{V} \times 7.0\text{ Ah} = \mathbf{49.0\text{ Watt-hora (Wh)}}$$
* **Estabilidad de Tensión Prolongada:** Con **7000 mAh** de capacidad, el consumo medio de "Smoke" ($\approx 800 - 1200\text{ mA}$ con todos los sistemas activos) representa apenas una tasa de descarga de $\approx 0.15\text{C}$.
* **Repetibilidad en Pista:** El vehículo puede rodar de forma continua durante más de **4 horas de entrenamiento intensivo** en el taller de INIAR sin que el voltaje del bus decaiga sensiblemente, garantizando que el comportamiento dinámico sea idéntico entre la primera y la última manga de competencia.

## 2.4 Regulación de Voltaje: Elevador XL6009 a 14V y Supresión de Caída L298N 
El driver clásico **L298N** implementa transistores bipolares de unión (BJT) en configuración Darlington para sus etapas de conmutación en puente H. Por física de semiconductores, estos transistores presentan una caída de tensión saturación colector-emisor interna inevitable:
$$V_{drop} = V_{CE(sat)} \approx 1.8\text{V} - 2.2\text{V}$$
Si el driver se conectara directamente a los 7.0V de la batería, el motor Makeblock apenas recibiría:
$$V_{motor} = 7.0\text{V} - 2.0\text{V} \approx 5.0\text{V}$$
Esto provocaría una pérdida crítica de torque de arranque y reduciría su velocidad angular a menos de 100 RPM.

### 2.4.1 Compensación de la Caída Interna del L298N
Para entregar los **12.0V netos de máxima eficiencia al motor Makeblock**:
1. Se retiró físicamente el puente (*jumper*) integrado de 5V del módulo L298N, desacoplando su regulador lineal interno 78M05 para evitar recalentamientos térmicos innecesarios.
2. Se calibró el módulo elevador **XL6009** a:
   $$V_{Boost} = V_{nominal} + V_{drop} = 12.0\text{V} + 2.0\text{V} = \mathbf{14.0\text{V DC}}$$
3. El pin $V_{ss}$ lógico del chip se alimenta directamente desde los 5V limpios del regulador XL4015, garantizando una conmutación lógica rápida y libre de ruido electromagnético.

> 🛡️ **Mitigación de Riesgo de Ingeniería:**
> **Para mitigar el riesgo de pérdida crítica de par motor, caída de velocidad lineal y estancamiento** provocado por la caída de tensión interna $V_{CE(sat)} \approx 2.0\text{V}$ en los transistores Darlington del driver L298N, elevamos la tensión del riel de tracción a **14.0V con el convertidor Step-Up XL6009**, asegurando que el motor Makeblock reciba 12.0V netos constantes y desarrolle su par nominal completo de $1.5\text{ kg}\cdot\text{cm}$ a 185 RPM.

### 2.4.2 Beneficios de la Tierra Común Unificada (Common Ground Plane)
Todos los polos negativos (GND) del banco de baterías 18650, los tres convertidores DC-DC, el driver L298N, los sensores ultrasónicos, el servo y el microcontrolador ESP32-S3 están **interconectados eléctricamente en un nodo de masa común**:
* **Referencia Equipotencial Cero:** Erradica bucles de tierra (*ground loops*) y tensiones parásitas flotantes que podrían provocar reinicios espontáneos en el procesador.
* **Integridad de Buses de Comunicación Serial (UART e I2C):** Al compartir un plano de 0V idéntico, las líneas de datos de alta velocidad (`Serial1` a 115,200 baudios de la HuskyLens 2 y las señales PWM del servo a 50 Hz) mantienen sus umbrales de nivel lógico $V_{IL}$ y $V_{IH}$ sin distorsiones ni lecturas corruptas.

### 2.4.3 Selección de Conductores: Cable 18 AWG Automotriz y Fijación por Borneras 
Para asegurar que la corriente fluya sin pérdidas resistivas ni riesgos térmicos desde el banco 2S2P hacia los tres convertidores DC-DC, el driver L298N y el motor Makeblock, se realizó una selección técnica específica de conductores y métodos de sujeción:

* **Descarte de Cable 14 AWG Convencional:** Durante las primeras fases de prueba se implementó cable de cobre estándar de calibre 14 AWG. Aunque ofrecía excelente capacidad de conducción, su aislamiento de PVC grueso y su elevada rigidez mecánica entorpecían enormemente el enrutamiento (*cable management*) dentro de los pisos del chasis ($225 \times 170\text{ mm}$), generando un sobrepeso innecesario y ejerciendo fuerzas de torsión que aflojaban las conexiones en las placas.
* **Adopción de Cable 18 AWG Automotriz (Alta Temperatura):** Se migró a cable automotriz multifilamento de **calibre 18 AWG**. Este tipo de conductor cuenta con una chaqueta polimérica de pared delgada diseñada para soportar ambientes térmicos exigentes, permitiendo tender las líneas de potencia muy cerca de los disipadores del driver L298N y de la carcasa del motor sin riesgo de degradación del aislante. Con una resistencia lineal de apenas $\approx 0.021\ \Omega/\text{m}$, tolera holgadamente los picos de más de $2.7\text{ A}$ demandados a las celdas Li-ion, manteniendo caídas de tensión despreciables ($\Delta V < 0.03\text{V}$).
* **Fijación Mecánica Exclusiva por Borneras de Tornillo (*Screw Terminals*):** En lugar de realizar soldaduras fijas en las líneas de potencia principales, **todos los empalmes entre baterías, switches, entradas/salidas de los tres convertidores DC-DC y el driver L298N se realizaron mediante borneras de tornillo**:
  1. **Modularidad y Mantenimiento Inmediato en Boxes:** Si un regulador requiere calibración de voltaje fino o sustitución urgente entre mangas oficiales, se desacopla en segundos utilizando un destornillador plano de precisión, sin depender de un cautín ni estresar térmicamente las pistas de cobre.
  2. **Inmunidad a Fracturas por Vibración:** Las borneras mecánicas aprisionan el conductor multifilamento de 18 AWG de forma homogénea, evitando las roturas por fatiga mecánica que suelen sufrir las soldaduras rígidas expuestas a las vibraciones continuas del chasis sobre la pista.
* **Segregación de Líneas Lógicas:** Los buses de comunicación sensible (I2C a 400 kHz y UART a 115,200 baudios) utilizan cables flexibles de 24 AWG, enrutados por canalizaciones separadas de las líneas de potencia de 18 AWG para erradicar cualquier acoplamiento inductivo (*crosstalk* o ruido EMI).

<div align="center">
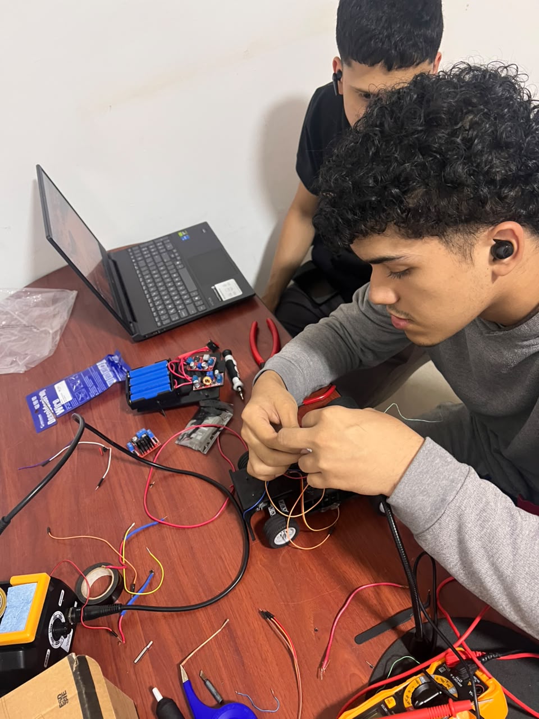
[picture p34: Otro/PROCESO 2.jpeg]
Integración Eléctrica y Cableado en Banco de Taller
  
  <br>
  <i><b>Figura 2.2:</b> Proceso de ensamble e integración eléctrica en banco de laboratorio: David y José pelando y organizando las líneas de potencia con cable automotriz 18 AWG, calibrando tensiones de corte con multímetro digital y conectando las etapas de regulación hacia el banco 2S2P y driver L298N.</i>
</div>

## 2.5 Selección, Compensaciones y Ubicación de Sensores Mediante la Geometría del Campo 
La arquitectura sensorial de **"Smoke"** opera bajo un esquema de **fusión sensorial distribuida**: combina visión artificial acelerada por hardware embebido para la clasificación semántica de obstáculos, con una red acústica de tiempo de vuelo para el mantenimiento de carril y telemetría inercial de alta frecuencia en tiempo real.
```mermaid
flowchart TD
    subgraph "ECOSISTEMA DE PERCEPCIÓN SENSORIAL SMOKE"
        US_F["📡 HC-SR04 Frontal\n(Gatillo de Curvas 90°  70 cm)"]
        US_R["📡 HC-SR04 Lateral Derecho\n(Centrado  30 cm / Escape  25 cm)"]
        US_L["📡 HC-SR04 Lateral Izquierdo\n(Centrado  30 cm / Escape  25 cm)"]
        MPU["🧭 IMU MPU6050 (Alineado al CoG)\n(Integración Yaw en Core 0 con FreeRTOS  500 Hz)"]
        HUSKY["👁️ HuskyLens 2 (IA KPU)\n(Reconocimiento de Color UART  115200 Baudios)"]
    end
    US_F & US_R & US_L -->|"Pulsos de Eco (Tiempo de Vuelo)"| ESP["🧠 Microcontrolador ESP32-S3"]
    MPU -->|"Bus I2C (Con Auto-Rescate de 9 Ciclos)"| ESP
    HUSKY -->|"Paquetes Seriales UART (GPIO 13 / 12)"| ESP
    classDef sens fill:#1f2328,stroke:#58a6ff,stroke-width:1px,color:#c9d1d9;
    classDef mcu fill:#0366d6,stroke:#24292e,stroke-width:2px,color:#fff;
    class US_F,US_R,US_L,MPU,HUSKY sens;
    class ESP mcu;
```

> 🛡️ **Mitigación de Riesgo de Ingeniería:**
> **Para mitigar el riesgo de diafonía acústica (*acoustic crosstalk*), aceleraciones centrífugas espurias e interferencias cruzadas en las comunicaciones**, la arquitectura distribuye los sensores física y temporalmente: la IMU MPU6050 se sitúa estrictamente concéntrica al centro de gravedad ($CoG$), la cámara HuskyLens 2 se segrega a un enlace serie UART punto a punto dedicado a 115,200 baudios, y el arreglo ultrasónico ejecuta un muestreo rotativo asíncrono con ventanas de guarda que erradica ecos parásitos.

### 2.5.0 Compensaciones de Sensores (*Sensor Trade-offs*) y Justificación Mediante la Geometría del Campo

Bajo la rúbrica oficial de la WRO (Criterio 2), la selección y disposición física de los sensores no obedece a criterios arbitrarios, sino a un estudio riguroso de **compensaciones (*trade-offs*) tecnológicas** y una **justificación geométrica basada en las dimensiones oficiales de la pista**:

| Sensor Implementado | Alternativa Descartada | Compensación Técnica (*Trade-off*) Aceptada | Ubicación Justificada Mediante la Geometría del Campo WRO |
| :--- | :--- | :--- | :--- |
| **Arreglo 3x HC-SR04**<br>(Tiempo de Vuelo Acústico) | **LiDAR 2D 360°**<br>(Escaneo Óptico Láser) | Se sacrificó un mapa de puntos denso en favor de **menor peso (26 g vs 190 g), mínimo consumo (<25 mA vs >400 mA) y total inmunidad a reflejos de luz** en las paredes blancas lacadas del campo. | **Montaje rasante a $25\text{ mm}$ del tapiz:** Las paredes perimetrales e isla central tienen una altura reglamentaria de $100\text{ mm}$. A $25\text{ mm}$, el cono acústico de $15^\circ$ viaja paralelo al suelo sin rebotar en irregularidades del tapiz ni dispersarse por encima del muro de madera. |
| **HuskyLens 2 IA**<br>(Inferencia KPU Embebida) | **Raspberry Pi 4 + Cámara USB**<br>(OpenCV en Linux Embebido) | Se sacrificó la flexibilidad de algoritmos en Python en favor de **arranque instantáneo (1.2 s vs 35 s en boxes), consumo térmico ínfimo (<1.6 W vs >15 W) y tasa determinista de 30 FPS**. | **Mástil a $65\text{ mm}$ con inclinación de $-8^\circ$ hacia abajo:** Los pilares cúbicos miden $100\text{ mm}$ de alto. Con un FOV horizontal de $60^\circ$ y el ángulo negativo de $-8^\circ$, la cámara divisa la base de los pilares a $12\text{ cm}$ del morro (evitando puntos ciegos bajo el vehículo) y detecta obstáculos lejanos a más de $1.2\text{ m}$. |
| **IMU MPU6050**<br>(Giroscopio / Acelerómetro I2C) | **Encoders Ópticos en Tren Delantero** | Se prescindió de encoders en las ruedas directrices para evitar holguras y cables móviles, confiando la odometría de rumbo a la integración inercial a 500 Hz. | **Ubicación Concéntrica al Centro de Gravedad ($CoG$):** Situado en el punto pivote geométrico en el Piso 2. Esta alineación anula las componentes de aceleración centrífuga espuria ($a_c = \omega^2 \cdot r$) que falsearían las lecturas en curvas si el sensor estuviera desplazado hacia los extremos. |

### 2.5.1 Cámara Neuronal HuskyLens 2 (IA / Visión por Color) 
Para superar el **Desafío de Obstáculos (Obstacle Challenge)**, el vehículo emplea el procesador de visión inteligente **HuskyLens 2** montado rígidamente en el Piso 2:
* **Ubicación Geométrica:** Situada a una cota de altura de **$65\text{ mm}$** respecto al suelo con un ángulo de inclinación negativo de **$8^\circ$ hacia abajo**. Esta perspectiva cónica permite abarcar la base de los pilares a $12\text{ cm}$ de distancia sin perder la visibilidad del obstáculo siguiente a más de $1.2\text{ m}$.
* **Inferencia Embebida en Hardware:** La cámara incorpora un procesador neuronal especializado (KPU) que ejecuta algoritmos de visión por computador internamente a **30 FPS**, liberando de carga al ESP32-S3.
* **Clasificación Colorimétrica Entrenada:** Identifica **Bloque Rojo (ID 1 - evasión por la derecha)** y **Bloque Verde (ID 2 - evasión por la izquierda)**.
* **Enlace UART Dedicado (115,200 Baudios):** Conectada a través de `Serial1` en los pines **GPIO 13 (RX)** y **GPIO 12 (TX)**, eliminando colisiones con el bus I2C.

### 2.5.2 Unidad de Medición Inercial MPU6050 (Giroscopio / Acelerómetro) 
El mantenimiento de rumbo rectilíneo y la verificación de giros de 90° se fundamentan en el sensor inercial **InvenSense MPU6050**:
* **Ubicación Geométrica Concéntrica al CoG:** Anclado matemáticamente en el **centro de gravedad ($CoG$) del vehículo en el Piso 2**. Al situar el sensor concéntrico con el eje de guiñada (*Yaw*), se anulan las aceleraciones centrífugas espurias ($a_c = \omega^2 \cdot r$) que falsearían las lecturas de aceleración si el sensor estuviera desfasado del centro.
* **Arquitectura Multitarea en Core 0 con FreeRTOS (500 Hz):** Tarea asíncrona dedicada que muestrea el giróscopo cada **$2\text{ ms}$** con integración trapezoidal del ángulo Yaw.
* **Tolerancia a Fallas en Hardware (Auto-Rescate I2C):** La subrutina `rescatarBusI2C()` inyecta **9 ciclos de reloj forzados en SCL** si detecta colapso del bus por ruido de conmutación, recuperando el sensor en menos de $150\ \mu\text{s}$.

### 2.5.3 Arreglo Perimetral de Ultrasonidos HC-SR04 
La detección perimetral de proximidad se basa en tres transductores ultrasónicos **HC-SR04** ubicados en el Piso 1 a una altura rasante de **$25\text{ mm}$**:
* **Justificación de Ubicación Geométrica:** A 25 mm del tapiz, el haz cónico de $15^\circ$ viaja paralelo al suelo sin rebotar contra irregularidades de la lona, detectando las paredes laterales de madera a la perfección.
* **Muestreo Rotativo Asíncrono (Anti-Crosstalk):** Secuencia no bloqueante cada 50 ms (`Frontal -> Derecho -> Frontal -> Izquierdo`), otorgando doble frecuencia de refresco al frontal para frenadas de emergencia sin interferencia acústica cruzada.
* **Filtrado de Outliers:** Descarte automático de lecturas nulas o timeouts mayores a $15,000\ \mu\text{s}$, devolviendo `999.0 cm` para evitar virajes erráticos.

## 2.6 Métodos de Calibración de Sensores y Procedimiento de Arranque 
Para asegurar repetibilidad absoluta entre mangas de competencia, se estandarizó un protocolo de calibración y encendido en tres fases:
1. **Fase 1: Estabilización Térmica y de Rieles (Switch 1 ON):** Conecta las celdas 18650 a los 3 convertidores DC-DC, permitiendo que los voltajes de 5V y 14V se estabilicen durante 5 segundos antes de alimentar la electrónica sensible.
2. **Fase 2: Arranque Lógico Limpio (Switch 2 ON):** Energiza el ESP32-S3 en un riel limpio. El firmware ejecuta la inicialización de buses I2C y UART, verificando la conexión con la HuskyLens 2 y la IMU con los actuadores forzados en bloqueo pasivo (PWM = 0, Servo = 96°).
3. **Fase 3: Calibración Estática Inercial (Pulsador GPIO 21):**
   * El vehículo se ubica inmóvil en la línea de salida sobre sus 4 ruedas.
   * Al presionar el botón de inicio en GPIO 21, el ESP32 recolecta **50 lecturas estáticas promediadas** de la velocidad angular en Z para determinar el sesgo de deriva ($gz_{offset}$).
   * Inmediatamente después, emite un pulso ultrasónico frontal para validar pista despejada y da inicio a la navegación autónoma.

## 2.7 Esquema Eléctrico Oficial, Pinout y Análisis de Puntos Únicos de Fallo (SPOF) 
El conexionado eléctrico integral de potencia, distribución de buses y líneas de control de **"Smoke"** fue desarrollado en **Fritzing** y se encuentra disponible en alta resolución en [`./Esquemas/DIAGRAMAVF.jpg`](./Esquemas/DIAGRAMAVF.jpg):
<div align="center">
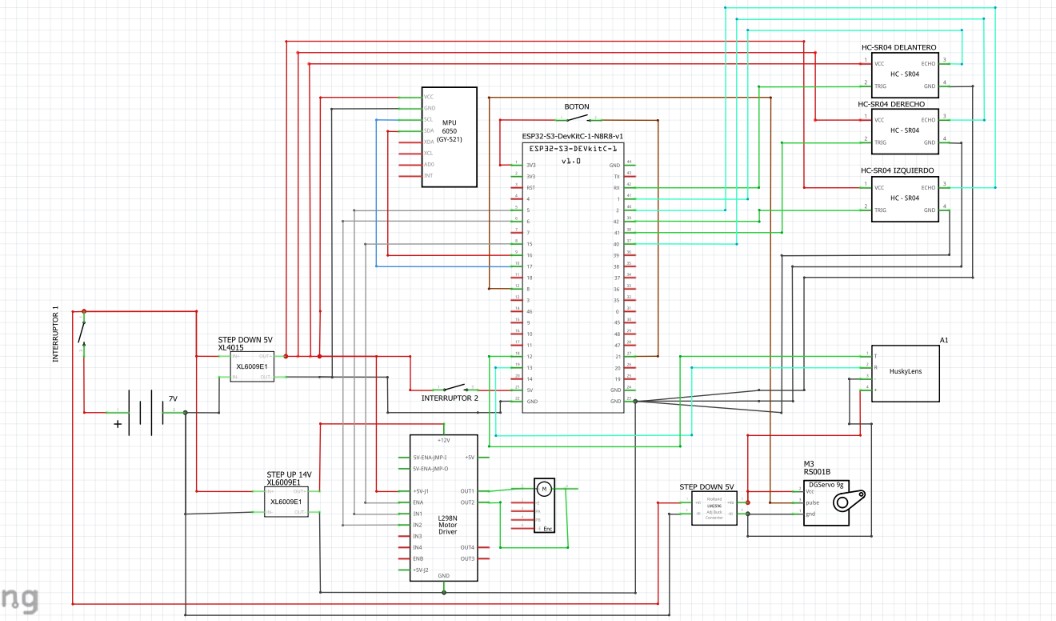
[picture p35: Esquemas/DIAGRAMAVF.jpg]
Esquemático Eléctrico Oficial Smoke
  
  <br>
  <i>Plano esquemático oficial de conexiones eléctricas de la plataforma autónoma "Smoke".</i>
</div>

### 2.7.1 Mapeo de Pines de Entrada y Salida (ESP32-S3 GPIO Allocation)
| Subsistema | Componente / Periférico | Pin Físico | Modo de Operación / Protocolo de Firmware |
| :--- | :--- | :---: | :--- |
| **🦾 Dirección** | Servomotor TowerPro MG90S | **GPIO 8** | Salida PWM a 50 Hz (Resolución de 12 bits con `ESP32Servo.h`) |
| **⚙️ Tracción** | Driver L298N – ENA (Velocidad) | **GPIO 15** | Modulación PWM a 1000 Hz (`ledcAttach` con ciclo de trabajo de 8 bits) |
| | Driver L298N – IN1 (Sentido) | **GPIO 5** | Salida digital: Estado ALTO (`HIGH`) para giro de avance |
| | Driver L298N – IN2 (Sentido) | **GPIO 6** | Salida digital: Estado BAJO (`LOW`) para avance / ALTO para freno |
| **👁️ Visión IA** | Cámara DFRobot HuskyLens 2 | **GPIO 13** | **UART RX** (Conectado a la línea TX de la cámara / `Serial1`) |
| | Cámara DFRobot HuskyLens 2 | **GPIO 12** | **UART TX** (Conectado a la línea RX de la cámara / `Serial1`) |
| **🧭 Orientación** | Sensor Inercial IMU MPU6050 | **GPIO 16** | Bus I2C – Línea de Datos bidireccional (**SDA** a 400 kHz) |
| | Sensor Inercial IMU MPU6050 | **GPIO 17** | Bus I2C – Línea de Reloj (**SCL** con auto-rescate en hardware) |
| **📡 Ultrasonido** | HC-SR04 Frontal (Curvas) | **GPIO 42** | Salida de Disparo (**TRIGGER**) – Pulso de $10\ \mu\text{s}$ |
| | HC-SR04 Frontal (Curvas) | **GPIO 41** | Entrada de Retorno (**ECHO**) – Medición por tiempo de vuelo |
| | HC-SR04 Derecho (Centrado) | **GPIO 38** | Salida de Disparo (**TRIGGER**) |
| | HC-SR04 Derecho (Centrado) | **GPIO 37** | Entrada de Retorno (**ECHO**) |
| | HC-SR04 Izquierdo (Centrado) | **GPIO 39** | Salida de Disparo (**TRIGGER**) |
| | HC-SR04 Izquierdo (Centrado) | **GPIO 40** | Entrada de Retorno (**ECHO**) |
| **🔘 Control Usuario** | Pulsador de Arranque en Pista | **GPIO 21** | Entrada digital con resistencia **Pull-Down** interna activada |

### 2.7.2 Análisis de Puntos Únicos de Fallo (Single Point of Failure - SPOF)
En ingeniería de sistemas críticos para WRO, se analizaron los posibles fallos eléctricos y sus mecanismos de mitigación integrados en "Smoke":

| Punto de Fallo Potencial (SPOF) | Efecto en el Sistema | Probabilidad | Severidad | Mitigación de Ingeniería Implementada |
| :--- | :--- | :---: | :---: | :--- |
| **Colapso del Bus I2C por Ruido Inductivo** | Pérdida de telemetría inercial Yaw; giro incontrolado del vehículo. | Media | Crítica | Rutina de hardware `rescatarBusI2C()` que conmuta pines a GPIO, genera 9 pulsos de reloj en SCL y reinicia el periférico en <150 µs sin detener la marcha. |
| **Pico de Corriente Inductiva por Servomotor** | Caída de tensión (*brownout*) y reinicio espontáneo del microcontrolador. | Alta | Crítica | Desacoplamiento físico en 3 ramas: el servomotor se alimenta de su propio regulador LM2596 (3A) independiente del XL4015 que alimenta al ESP32. |
| **Pérdida de Paquetes en Visión HuskyLens** | Fallo en la detección de obstáculos de color rojo o verde. | Baja | Alta | Migración de bus compartido I2C a enlace serie UART punto a punto por hardware a 115,200 baudios con buffer circular en FIFO. |
| **Vibración y Desconexión de Cables Jumper** | Falso contacto en pines de alimentación o señales de sensores. | Media | Alta | Soldadura directa en placa PCB de distribución con conectores JST reforzados con pegamento caliente en los terminales del chasis. |
<p align="right"><a href="#indice-general">⬆️ Volver al Índice</a></p>

# 💻 Módulo 3: Arquitectura de Software y Control Autónomo 
El software embebido de **"Smoke"** fue desarrollado en **C++ bajo el entorno Arduino IDE**, optimizado específicamente para el microcontrolador de doble núcleo **ESP32-S3**. 
Para garantizar un control en tiempo real estricto, el código opera bajo una **arquitectura asíncrona no bloqueante gobernada por el sistema operativo en tiempo real FreeRTOS y temporizadores de hardware (`millis()`)**, evitando por completo el uso de funciones bloqueantes tipo `delay()` en los bucles de carrera.
El código fuente oficial de la ronda abierta se encuentra alojado en [`./src/OPENCHALLENGE/NUMERO4.ino`](./src/OPENCHALLENGE/NUMERO4.ino) y el de la ronda de obstáculos en [`./src/CLOSECHALLENGE/OBSTACULO_2.ino`](./src/CLOSECHALLENGE/OBSTACULO_2.ino) (con su versión preliminar histórica preservada en [`./src/CLOSECHALLENGE/legacy/CAZA_NUMERO1.ino`](./src/CLOSECHALLENGE/legacy/CAZA_NUMERO1.ino)).

## 3.1 Arquitectura General y Máquina de Estados Finitos (FSM) 
El flujo de control de carrera se rige mediante una máquina de estados finitos determinista que administra las transiciones entre la calibración estática, el guiado reactivo en rectas y las maniobras de viraje en esquinas:
```mermaid
flowchart TD
    BOOT["🔌 BOOT_SAFETY:\nBloqueo Pasivo de Actuadores\n(Motor a 0V / Servo Centrado a 96°)"] --> WAIT_BTN{"🔘 WAIT_START:\n¿Pulsador GPIO 21\nPresionado?"}
    
    WAIT_BTN -- No --> WAIT_BTN
    WAIT_BTN -- Sí --> CALIB["🧭 CALIB_MPU:\nCalibración Offset IMU MPU6050\n(50 Muestras / Tarea FreeRTOS Core 0  500 Hz)"]
    
    CALIB --> DRIVE["🏎️ NAV_STRAIGHT:\nAvance con Controlador PD de Rumbo\n(Corrección por Yaw MPU + Escape Lateral US)"]
    
    DRIVE --> CHECK_CORNER{"📡 HC-SR04 Frontal\n¿Distancia ≤ 70 cm?"}
    
    CHECK_CORNER -- No --> DRIVE
    CHECK_CORNER -- Sí --> DETECT_DIR{"¿Primera Esquina?\n(direccion_giro == 0)"}
    
    DETECT_DIR -- Sí --> EVAL_SPACE["EVAL_SENSE:\nComparar US Izq vs Der\n(Fijar Sentido Horario / Antihorario)"]
    EVAL_SPACE --> TURN["🔄 CORNER_TURN:\nManiobra de Viraje a 90°\n(Servo Deflexión ±21° / Setpoint ±89°)"]
    DETECT_DIR -- No --> TURN
    
    TURN --> CHECK_END{"¿Esquinas ≥ 12?\n(3 Vueltas Completas)"}
    
    CHECK_END -- No --> COOLDOWN["⏱️ COOLDOWN_GIRO:\nPausa de Inmunidad (500 ms)\nRetorno a Setpoint"] --> DRIVE
    CHECK_END -- Sí --> STOP["🛑 END_RACE:\nParada Segura tras Cruce de Meta\n(Frenado Regenerativo Motor / Servo a 96°)"]
    classDef state fill:#1f2328,stroke:#58a6ff,stroke-width:1px,color:#c9d1d9;
    classDef dec fill:#0366d6,stroke:#24292e,stroke-width:2px,color:#fff;
    classDef stop fill:#d73a49,stroke:#24292e,stroke-width:2px,color:#fff;
    class BOOT,CALIB,DRIVE,EVAL_SPACE,TURN,COOLDOWN state;
    class WAIT_BTN,CHECK_CORNER,DETECT_DIR,CHECK_END dec;
    class STOP stop;
```

## 3.2 Estrategia de Seguimiento de Carril: Open Challenge (`NUMERO4.ino`) 
El firmware de la ronda abierta se encuentra estructurado en cuatro módulos funcionales que operan de forma asíncrona mediante temporizadores de hardware:
---
### 3.2.1 Inicialización, Concurrencia y Configuración de Periféricos 
Para evitar que el robot sufra arranques violentos e incontrolados al energizar el microcontrolador, la función `setup()` ejecuta una secuencia de seguridad pasiva inmediata que bloquea los actuadores antes de inicializar las comunicaciones:
* **Freno de Motores:** Se configuran los canales PWM forzando la velocidad a cero y los pines `PIN_MOTOR_IN1` y `PIN_MOTOR_IN2` en estado bajo (`LOW`).
* **Centrado Mecánico:** El servo MG90S se clava de inmediato en su ángulo neutro (`SERVO_CENTRO = 96°`).
* **Despliegue de Tarea en Core 0:** Se crea la tarea `tareaLeerMPU` asignada al **Core 0** del ESP32-S3 mediante `xTaskCreatePinnedToCore()`, garantizando un bucle inercial a **500 Hz (cada 2 ms)** totalmente inmune a las demoras del resto del programa.
```cpp
// --- Fragmento Setup: Bloqueo de seguridad pasiva ---
pinMode(PIN_MOTOR_IN1, OUTPUT); 
pinMode(PIN_MOTOR_IN2, OUTPUT);
digitalWrite(PIN_MOTOR_IN1, LOW); 
digitalWrite(PIN_MOTOR_IN2, LOW);
// Bloquear velocidad PWM a cero
ledcAttach(PIN_MOTOR_PWM, 1000, 8); 
ledcWrite(PIN_MOTOR_PWM, 0); 
// Centrar inmediatamente el servomotor
ledcAttach(PIN_SERVO, 50, 12); 
escribirServoGrados(SERVO_CENTRO);
// Lanzamiento de tarea en tiempo real en Core 0 para el MPU6050
xTaskCreatePinnedToCore(tareaLeerMPU, "TareaMPU", 4096, NULL, 2, &TareaMPU, 0);
```

> 🛡️ **Mitigación de Riesgo de Ingeniería:**
> **Para mitigar el riesgo de arranques violentos e incontrolados (*uncontrolled startup*)** al energizar el circuito o durante el posicionamiento manual en la celda de partida por parte del operador, la función `setup()` bloquea el PWM en 0, coloca en bajo las líneas de dirección del motor y clava el servo en 96° antes de habilitar el botón de arranque.

### 3.2.2 Percepción Ultrasónica y Detección Dinámica de Esquinas 
El vehículo elimina cualquier dependencia de configuración manual previa a la carrera, detectando de forma autónoma el sentido del circuito reglamentario:
* **Calibración Estática en Salida:** Al presionar el pulsador de inicio (`PIN_INICIO` en GPIO 21), el ESP32 recolecta 50 muestras estáticas de la velocidad angular en Z para determinar el offset de deriva (`gz_offset`) mientras el chasis permanece en reposo.
* **Decisión Autónoma de Sentido (Horario / Antihorario):** En la primera curva (`direccion_giro == 0`), el sensor ultrasónico frontal detecta el muro a $\le 70\text{ cm}$ y el firmware compara automáticamente las lecturas laterales para fijar el sentido de carrera:
```cpp
// Detección autónoma del sentido de pista en la primera esquina
if (direccion_giro == 0) {
  if (dist_izquierda >= dist_derecha) {
    direccion_giro = 1; // Sentido Antihorario (Pista con giros a la Izquierda)
    Serial.println(">>> PRIMERA ESQUINA: MÁS ESPACIO A LA IZQ. GUARDANDO GIRO A LA IZQUIERDA.");
  } else {
    direccion_giro = -1; // Sentido Horario (Pista con giros a la Derecha)
    Serial.println(">>> PRIMERA ESQUINA: MÁS ESPACIO A LA DER. GUARDANDO GIRO A LA DERECHA.");
  }
}
```
### 3.2.3 Control PD de Heading con Giróscopo y Maniobra de Escape 
Durante el tránsito por los tramos rectos de la pista, el firmware ejecuta un lazo de control cada **1 ms** (`TIEMPO_LECTURA_MS = 1`):
* **Controlador Proporcional-Derivativo (PD):** Compara el rumbo objetivo (`setpoint_efectivo`) contra el ángulo inercial integrado (`yaw_actual`). Si el error angular supera la **zona muerta de $\pm 2.0^\circ$**, modula la timonería del servomotor MG90S con constantes $K_p = 1.0$ y $K_d = 0.0$.
* **Escape Lateral Reactivo:** Los sensores ultrasónicos laterales vigilan la proximidad a las paredes. Si la distancia en cualquiera de los flancos cae por debajo del umbral de seguridad de **$25.0\text{ cm}$** (`DISTANCIA_MIN_LATERAL`), el firmware inyecta un offset angular instantáneo de $\pm 25^\circ$ (`ANGULO_ESCAPE`), alejando al vehículo del muro sin perder la referencia global de rumbo.

> 🛡️ **Mitigación de Riesgo de Ingeniería:**
> **Para mitigar el riesgo de oscilaciones parásitas de alta frecuencia (*hunting/jitter*) y sobrecalentamiento térmico del servomotor** causadas por el ruido de integración del giróscopo en tramos rectos, se implementó una zona muerta (*deadband*) de $\pm 2.0^\circ$ y una corrección lateral de escape condicionada estrictamente a la invasión de la cota perimetral de $25.0\text{ cm}$.
```cpp
// Lazo de control PD inercial
float setpoint_efectivo = setpoint_yaw + offset_lateral;
float error = setpoint_efectivo - yaw_actual;
// Zona muerta para evitar oscilaciones de alta frecuencia en el servo
if (abs(error) < ZONA_MUERTA) { 
  error = 0.0; 
  error_anterior = 0.0; 
}
float derivada = (error - error_anterior) / dt;
error_anterior = error;
float correccion = (Kp * error) + (Kd * derivada);
correccion = constrain(correccion, -MAX_DEFLEXION, MAX_DEFLEXION);
// Subrutina de escape lateral reactivo ante aproximación a muros
if (dist_derecha < DISTANCIA_MIN_LATERAL)   offset_lateral -= ANGULO_ESCAPE;
if (dist_izquierda < DISTANCIA_MIN_LATERAL) offset_lateral += ANGULO_ESCAPE;
```
### 3.2.4 Negociación Determinista de Curvas y Conteo de 12 Esquinas 
El viraje en las esquinas reglamentarias se ejecuta bajo una rutina sincronizada de precisión:
1. **Disparo de Giro:** Al detectar muro frontal a $\le 70\text{ cm}$ con espacio lateral despejado ($\ge 70\text{ cm}$), el servomotor se posiciona en máxima deflexión angular (`MAX_DEFLEXION = 21°`), se actualiza el setpoint en $\pm 89^\circ$ y se incrementa el contador de esquinas (`esquinas_contadas++`).
2. **Criterio de Salida de Curva:** La maniobra se considera completada cuando el error angular respecto al setpoint es menor a $8.0^\circ$ o si transcurre el tiempo límite de seguridad (`TIMEOUT_GIRO = 2500 ms`), retornando al modo de avance rectilíneo con un período de enfriamiento (*cooldown*) de $500\text{ ms}$.
3. **Parada Automática tras 3 Vueltas (12 Esquinas):** Al registrar 12 esquinas válidas, el robot activa el estado de fin de carrera: mantiene la inercia durante $1500\text{ ms}$ para cruzar holgadamente la línea de meta, corta el PWM del motor Makeblock, conecta los pines IN1 e IN2 a nivel bajo para inducir frenado regenerativo y clava el servo al centro.
```cpp
// Registro de esquinas y activación de fin de carrera tras 12 giros
if (esquinas_contadas >= 12 && !carrera_terminada) {
  carrera_terminada = true;
  tiempo_fin_carrera = tiempo_actual;
  Serial.println(">>> 12 ESQUINAS ALCANZADAS. APAGANDO EN EL TIEMPO SETEADO...");
}
// Secuencia de parada final tras cruzar la línea de meta
if (carrera_terminada && !motor_frenado) {
  if (tiempo_actual - tiempo_fin_carrera >= TIEMPO_PARO_FIN) {
    digitalWrite(PIN_MOTOR_IN1, LOW);
    digitalWrite(PIN_MOTOR_IN2, LOW);
    ledcWrite(PIN_MOTOR_PWM, 0);       // Corte de potencia al motor
    escribirServoGrados(SERVO_CENTRO); // Centrado de timonería a 96°
    motor_frenado = true;
    Serial.println("\n=== 12 ESQUINAS COMPLETADAS - MOTOR APAGADO ===");
  }
}
```

## 3.3 Estrategia de Obediencia a Obstáculos: Obstacle Challenge (`OBSTACULO_2.ino`) 
La ronda de obstáculos (Obstacle Challenge) eleva exponencialmente la complejidad del sistema respecto a la ronda abierta: el vehículo ya no solo debe navegar dentro del carril delimitado por las paredes, sino también **detectar, clasificar y evadir dinámicamente obstáculos cúbicos de color rojo y verde** distribuidos de forma aleatoria a lo largo de las tres vueltas reglamentarias.
Para cumplir con las normas de la WRO Future Engineers 2026:
- **Obstáculo Rojo (ID 1):** Obliga a pasar por su flanco derecho (dejando el obstáculo a la izquierda del robot).
- **Obstáculo Verde (ID 2):** Obliga a pasar por su flanco izquierdo (dejando el obstáculo a la derecha del robot).

El firmware oficial de competición **`OBSTACULO_2.ino`** (evolución optimizada del prototipo inicial [`CAZA_NUMERO1.ino`](./src/CLOSECHALLENGE/legacy/CAZA_NUMERO1.ino) preservado en la carpeta `legacy/`) adopta una arquitectura de **control híbrido concurrente en FreeRTOS**: un lazo inercial de alta frecuencia en el **Core 0** (500 Hz), enlazado a un planificador reactivo en el **Core 1** que interconecta la visión por IA de la HuskyLens 2 cada 30 ms, un **algoritmo cazador proporcional con ganancias desacopladas por color**, una **rutina de cabeceo/barrido activo sinusoidal para búsqueda de cubos**, y un **secuenciador de maniobra evasiva en 5 etapas**.

```mermaid
flowchart TD
    A([Inicio de Ronda Cerrada]) --> B[Navegación Base en Recta / Cabeceo Activo]
    B --> C{¿HuskyLens detecta Bloque?}
    C -- No --> B
    C -- Sí --> D[Filtro Espacial y de Tamaño: Ancho >= 70 px]
    D --> E{¿Pasa Máscara de Exclusión?}
    E -- No --> B
    E -- Sí --> F["Modo Cazador Proporcional (KP_CENTRAR = 0.005)"]
    F --> G{¿Ancho Bloque >= 180 px?}
    G -- No --> F
    G -- Sí --> H["Fase 0: Latigazo Evasivo Proporcional (KP_ROJO=0.009 / KP_VERDE=0.010)"]
    H --> I["Fase 1: Escape Diagonal de Seguridad (100 ms)"]
    I --> J["Fase 2: Retorno Consciente y Simétrico por Color"]
    J --> K["Fase 3: Alineación Pre-Reversa con PID (1000 ms)"]
    K --> L["Fase 4: Reversa Post-Esquive de Desenganche (1300 ms)"]
    L --> M["Fase 5: Cabeceo Activo de Búsqueda de Nuevos Cubos (1500 ms)"]
    M --> B
```

### 3.3.1 Concurrencia Multihilo en FreeRTOS y Odometría Inercial Discreta (Core 0 @ 500 Hz) 
En la ronda de obstáculos, la ESP32-S3 debe atender dos exigencias temporales en conflicto:
1. **Flujo perceptual asíncrono y bloqueante:** La comunicación con la cámara HuskyLens 2 vía UART a 115200 baudios y el muestreo por tiempo de vuelo de los tres sensores ultrasónicos (HC-SR04) introducen latencias variables de entre 15 ms y 60 ms por ciclo.
2. **Integración angular continua:** El cálculo del rumbo (Yaw) a través de la velocidad angular del giróscopo requiere una tasa de refresco ultra estricta y periódica; cualquier variación en el intervalo de integración produce una deriva acumulada inaceptable que desorientaría al vehículo durante las maniobras de evasión.
Para resolver este desacoplo, se implementa una arquitectura simétrica en **FreeRTOS** fijando la tarea inercial al núcleo secundario (**Core 0**), mientras el hilo principal (`loopTask`) opera en el **Core 1** con un stack extendido a 16 KB (`SET_LOOP_TASK_STACK_SIZE(16384)`).
---
##### 1. Formulación Matemática de la Odometría Inercial Discreta
La orientación angular instantánea $\theta(t)$ en el plano de la pista se obtiene mediante la discretización de la integral de velocidad angular sobre el eje Z:

$$\theta_k = \theta_{k-1} + (\omega_{z,k} - b_z) \cdot \Delta t_k \cdot \left(\frac{180^\circ}{\pi}\right)$$
Donde:

- $\theta_k$: Ángulo de rumbo actual (Yaw) en grados sexagesimales ($^\circ$).
- $\omega_{z,k}$: Velocidad angular cruda leída del registro `gyro.z` en radianes por segundo (rad/s).
- $b_z$: Sesgo estático del giróscopo (calculado durante la rutina de calibración previa al arranque mediante el promedio de $N = 2000$ muestras estacionarias):
$$b_z = \frac{1}{N} \sum_{i=1}^{N} \omega_{z,i}$$

- $\Delta t_k = t_k - t_{k-1}$: Paso de integración temporal real medido en microsegundos mediante `micros()`.
- **Filtro de Banda Muerta (Deadband):** Para eliminar la acumulación de ruido gaussiano de baja amplitud cuando el robot se encuentra detenido o en avance rectilíneo, se aplica una función no lineal de supresión de umbral:

$$\omega_{z,\text{filtrada}} = \begin{cases} 0 & \text{si } |\omega_{z,k} - b_z| < U_r \\ (\omega_{z,k} - b_z) & \text{en otro caso} \end{cases}$$

Donde el umbral de ruido configurado es:
$$U_r = 0.015 \text{ rad/s} \quad (\approx 0.859^\circ/\text{s})$$

##### 2. Asignación de Pines e Inicialización de Periféricos
| Periférico | Pin Físico (GPIO) | Protocolo / Modo | Función en Ronda Cerrada |
| :--- | :--- | :--- | :--- |
| **MPU6050 SDA** | `GPIO 16` | I2C Fast-Mode (400 kHz) | Línea bidireccional de datos inerciales. |
| **MPU6050 SCL** | `GPIO 17` | I2C Fast-Mode (400 kHz) | Señal de reloj sincronizada de la IMU. |
| **HuskyLens RX** | `GPIO 13` | Serial1 UART (115200 baud) | Recepción de paquetes de visión por IA. |
| **HuskyLens TX** | `GPIO 12` | Serial1 UART (115200 baud) | Transmisión de peticiones a la cámara. |
| **Servo MG90S** | `GPIO 8` | PWM @ 50 Hz (LEDC) | Actuador del sistema de dirección Ackermann. |
| **Motor DC PWM** | `GPIO 15` | PWM @ 1000 Hz (LEDC) | Control de velocidad modulada del tren motriz. |
| **Puente H IN1** | `GPIO 5` | GPIO Output | Sentido de giro tracción trasera. |
| **Puente H IN2** | `GPIO 6` | GPIO Output | Sentido de giro tracción trasera. |
| **Pulsador Inicio** | `GPIO 21` | GPIO Input Pulldown | Disparo de calibración y cuenta regresiva. |
| **Trig Frontal** | `GPIO 42` | GPIO Output | Pulso de disparo ultrasónico frontal. |
| **Echo Frontal** | `GPIO 41` | GPIO Input | Medición de ancho de pulso frontal. |
| **Trig / Echo Der**| `GPIO 38 / 37` | Input / Output | Telemetría perimetral derecha. |
| **Trig / Echo Izq**| `GPIO 39 / 40` | Input / Output | Telemetría perimetral izquierda. |
---
##### 3. Implementación en C++ / FreeRTOS (`Core 0`)
```cpp
#include <Adafruit_MPU6050.h>
#include <Adafruit_Sensor.h>
#include <Wire.h>
#include <DFRobot_HuskylensV2.h> 
// Instancias de los dispositivos de percepción
Adafruit_MPU6050 mpu;
HuskylensV2 huskylens;           
// Ampliación del stack de FreeRTOS para la tarea principal en Core 1
SET_LOOP_TASK_STACK_SIZE(16384);
// --- Mapa de Entradas / Salidas ---
const int PIN_SERVO     = 8;
const int PIN_MOTOR_PWM = 15;
const int PIN_MOTOR_IN1 = 5;
const int PIN_MOTOR_IN2 = 6;
const int PIN_INICIO    = 21;
const int PIN_SDA = 16;
const int PIN_SCL = 17;
const int RX_HUSKY = 13;
const int TX_HUSKY = 12;
const int PIN_TRIG_FRONTAL   = 42;
const int PIN_ECHO_FRONTAL   = 41;
const int PIN_TRIG_DERECHO   = 38;
const int PIN_ECHO_DERECHO   = 37;
const int PIN_TRIG_IZQUIERDO = 39;
const int PIN_ECHO_IZQUIERDO = 40;
// Variables globales de odometría protegidas para concurrencia
volatile float angulo_actual = 0.0;
float sesgo_giroscopio_z = 0.0;
const float UMBRAL_RUIDO_RADS = 0.015; // Banda muerta (~0.86 deg/s)
// --- Tarea Crítica de Muestreo Inercial en Core 0 (500 Hz) ---
void tareaLeerMPU(void *pvParameters) {
  unsigned long tiempo_previo = micros();
  
  for (;;) {
    sensors_event_t a, g, temp;
    mpu.getEvent(&a, &g, &temp);
    
    unsigned long tiempo_actual = micros();
    float dt = (tiempo_actual - tiempo_previo) / 1000000.0;
    tiempo_previo = tiempo_actual;
    // Descuento de sesgo de calibración
    float gz = g.gyro.z - sesgo_giroscopio_z;
    // Aplicación del filtro de banda muerta no lineal
    if (abs(gz) > UMBRAL_RUIDO_RADS) {
      angulo_actual += (gz * RAD_TO_DEG) * dt;
    }
    // Retardo periódico estricto de 2 ms (frecuencia de integración = 500 Hz)
    vTaskDelay(pdMS_TO_TICKS(2));
  }
}
void calibrarMPU() {
  const int NUM_MUESTRAS = 2000;
  float acumulador = 0.0;
  
  for (int i = 0; i < NUM_MUESTRAS; i++) {
    sensors_event_t a, g, temp;
    mpu.getEvent(&a, &g, &temp);
    acumulador += g.gyro.z;
    delayMicroseconds(1000);
  }
  sesgo_giroscopio_z = acumulador / NUM_MUESTRAS;
}
void setup() {
  // Inicialización de buses de comunicación
  Wire.begin(PIN_SDA, PIN_SCL);
  Wire.setClock(400000); // Modo I2C rápido
  Serial1.begin(115200, SERIAL_8N1, RX_HUSKY, TX_HUSKY);
  pinMode(PIN_INICIO, INPUT_PULLDOWN);
  
  // Configuración de la IMU MPU6050
  if (mpu.begin()) {
    mpu.setGyroRange(MPU6050_RANGE_500_DEG);
    mpu.setFilterBandwidth(MPU6050_BAND_21_HZ); // Filtro pasabajas analógico interno
    calibrarMPU();
  }
  // Enlace con la cámara HuskyLens 2
  while (!huskylens.begin(Serial1)) {
    delay(100);
  }
  // Creación y fijación del hilo de odometría en Core 0
  xTaskCreatePinnedToCore(
    tareaLeerMPU,       // Función ejecutora
    "TareaInercial_C0", // Etiqueta descriptiva
    4096,               // Profundidad de pila
    NULL,               // Parámetros de entrada
    1,                  // Prioridad de ejecución
    NULL,               // Handle de la tarea
    0                   // Afinidad de procesador: Núcleo 0
  );
}
```

### 3.3.2 Percepción por Visión IA, Filtrado Espacial de Borde y Modo Cazador Proporcional 
En el Obstacle Challenge de la WRO, la cámara neuronal **HuskyLens 2** opera en modo *Color Recognition* (reconocimiento de color por redes neuronales convolucionales embebidas), clasificando los pilares de la pista en dos clases semánticas:
- **ID 1 (Rojo):** Señalización reglamentaria que obliga al robot a dejar el obstáculo a su izquierda (evasión por la derecha).
- **ID 2 (Verde):** Señalización reglamentaria que obliga al robot a dejar el obstáculo a su derecha (evasión por la izquierda).
Sin embargo, ejecutar una evasión ciega en cuanto el objeto aparece en el campo de visión periférico produce colisiones contra las paredes laterales de la pista. Para garantizar una aproximación determinista, el sistema implementa un preprocesamiento espacial en dos etapas: **Filtrado de Bordes Ciegos** y el **Algoritmo de Caza Proporcional**.

##### 1. Modelado Matemático y Filtrado Óptico
El sensor óptico de la HuskyLens entrega las coordenadas de los bloques delimitadores (*bounding boxes*) en una matriz de resolución de $640 \times 480 \text{ px}$.
           
###### A. Filtro de Falsos Positivos en Borde de Pista
En curvas cerradas, las paredes de madera blanca reflejan tonalidades o capturan pilares de secciones contiguas de la pista en el extremo del sensor. Si se procesa un obstáculo rojo muy pegado al borde izquierdo absoluto ($X < 10$), el robot intentaría esquivar hacia el centro de la pista cuando en realidad el obstáculo está fuera de carril. Por tanto, se define una máscara de exclusión espacial:

$$\text{Validez}(\text{Bloque}) = \begin{cases} \text{FALSO} & \text{si } (\text{ID} = 1 \land X_c < 10) \lor (\text{ID} = 2 \land X_c > 630) \\ \text{VERDADERO} & \text{en cualquier otro caso} \end{cases}$$

> 🛡️ **Mitigación de Riesgo de Ingeniería:**
> **Para mitigar el riesgo de falsos positivos ópticos, detecciones erróneas por reflejos especulares en los muros blancos y virajes bruscos prematuros**, el software evalúa una máscara de exclusión espacial que anula detecciones en bordes extremos ($X < 10\text{ px}$ y $X > 630\text{ px}$) y exige una persistencia mínima de 3 ciclos de inferencia ($100\text{ ms}$) antes de autorizar la transición de la máquina de estados hacia el modo de evasión activa.

###### B. Ley de Control del Modo Cazador Proporcional (Centrado Dinámico y Latigazo Desacoplado)
En lugar de esquivar de inmediato con una trayectoria curva incierta, el vehículo primero **apunta directamente hacia el centro del obstáculo** para enfrentar la maniobra en ángulo perfectamente normal ($90^\circ$ respecto a la cara del pilar).
El error de desalineación horizontal respecto al centro óptico ($X_{\text{ref}} = 320 \text{ px}$) se define como:

$$e_X(t) = X_c(t) - X_{\text{ref}}$$
La corrección aplicada sobre el ángulo de la servodirección Ackermann ($\theta_{\text{servo}}$) desacopla la ganancia de persecución lejana de las ganancias de latigazo evasivo:

$$\Delta \theta(t) = \begin{cases} K_{p,\text{centrar}} \cdot e_X(t) & \text{si } W_{\text{px}} < W_{\text{inicio\_esquive}} \\ K_{p,\text{esquive}} \cdot e_{X,\text{extremo}} & \text{si } W_{\text{px}} \ge W_{\text{inicio\_esquive}} \end{cases}$$

$$\theta_{\text{servo}}(t) = \text{constrain}\left(\theta_0 + \Delta \theta(t), \, \theta_0 - \delta_{\max}, \, \theta_0 + \delta_{\max}\right)$$

Donde:
- $\theta_0 = 96^\circ$ (Posición central calibrada de la servodirección).
- $\delta_{\max} = 21^\circ$ (Deflexión máxima física admitida por el chasis).
- $K_{p,\text{centrar}} = 0.005$ (Ganancia de persecución lejana y centrado suave).
- $K_{p,\text{esquive, rojo}} = 0.009$ vs $K_{p,\text{esquive, verde}} = 0.010$ (Ganancias independientes de evasión rápida según color).
- $W_{\min} = 70\text{ px}$ (Filtro que ignora objetos lejanos o reflejos ópticos menores).
- $W_{\text{inicio\_esquive}} = 180\text{ px}$ (Gatillo de inicio de latigazo evasivo).

###### C. Rutina de Barrido y Cabeceo Activo (*Active Sweeping / Scanning*)
Al concluir una curva de 90° o finalizar la maniobra evasiva de un pilar, el robot activa automáticamente una **rutina de cabeceo sinusoidal (`HABILITAR_CABECEO = true`)**:
Durante un intervalo de $1500\text{ ms}$, el servomotor barre un arco oscilatorio de $\pm 40^\circ$ con velocidad angular controlada ($\omega_{\text{sweep}} = 0.006$) y un periodo de estabilización inercial de $300\text{ ms}$. Esto amplía el campo de visión efectivo de la HuskyLens 2, garantizando la detección inmediata del siguiente obstáculo aunque haya quedado fuera del eje óptico frontal.

##### 2. Implementación en C++ (`Core 1` - `OBSTACULO_2.ino`)
```cpp
// =========================================================
// ---> PARÁMETROS DE CABECEO (BÚSQUEDA DE CUBOS) <---
// =========================================================
bool HABILITAR_CABECEO       = true;    // Activa o desactiva la función
unsigned long TIEMPO_CABECEO = 1500;    // ms de vaivén al terminar maniobras
float AMPLITUD_CABECEO       = 40.0;    // Amplitud angular del barrido
float VELOCIDAD_CABECEO      = 0.006;   // Frecuencia del vaivén sinusoidal
unsigned long TIEMPO_ESTABILIZACION = 300; // ms para calmar inercia

// =========================================================
// ---> CONTROL DE ESQUIVE VISUAL FLUIDO (CAZADOR) <---
// =========================================================
float KP_CENTRAR        = 0.005;  // Perseguir y centrar el cubo desde lejos
float KP_ESQUIVE_ROJO   = 0.009;  // Latigazo para esquivar ROJO
float KP_ESQUIVE_VERDE  = 0.010;  // Latigazo para esquivar VERDE

int MIN_WIDTH_ESQUIVE    = 70;   // Menor a 70 px = lo ignora (filtro de ruido)
int WIDTH_INICIO_ESQUIVE = 180;  // Entre 70 y 180 centra; >= 180 gatilla evasión
int BORDE_IZQ            = -100; // Objetivo extremo izquierdo
int BORDE_DER            = 740;  // Objetivo extremo derecho
```

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

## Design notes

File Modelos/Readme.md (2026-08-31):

# ⚙️ Modelos 3D y Diseño Mecánico – Team Nexus
En esta sección se encuentran todos los componentes mecánicos diseñados y modelados en 3D para el vehículo autónomo de **Team Nexus (WRO 2026)**.
---
## 🏎️ **Filosofía del Diseño Mecánico y Arquitectura por Capas**
Para optimizar el centro de masa, el aislamiento eléctrico y facilitar el mantenimiento rápido durante la competencia, el chasis se estructuró en una **arquitectura vertical de 3 niveles**:
| Nivel / Piso | Componentes Instalados | Propósito de Ingeniería y Justificación |
| :--- | :--- | :--- |
| **🏢 Nivel 3**<br>*(Techo / Superior)* | • Portabaterías<br>• Regulador Buck (Step-Down 5V)<br>• *Futuro módulo Step-Up (Boost)* | **Gestión de Potencia:**<br>• Acceso rápido para reemplazo de baterías entre rondas.<br>• Aislamiento térmico y eléctrico de la fuente de poder principal.<br>• Separación de líneas para evitar caídas de tensión en el microcontrolador. |
| **🧠 Nivel 2**<br>*(Intermedio / Lógica)* | • Microcontrolador ESP32<br>• Cámara HuskyLens<br>• Giroscopio / IMU *(en el centro de masa)*<br>• Driver de motor DC<br>• Protoboard de desarrollo | **Cerebro y Navegación:**<br>• **IMU en el centro geométrico** para evitar aceleraciones tangenciales y lecturas de giro erróneas.<br>• **HuskyLens** con línea de visión despejada y altura ideal para detección de bloques.<br>• Centralización de señales de control. |
| **⚙️ Nivel 1**<br>*(Base / Inferior)* | • Motor DC de tracción trasera<br>• Servomotor de dirección + brazo impreso<br>• 3x Sensores Ultrasónicos (1 frontal, 2 laterales) | **Tracción, Dirección y Sensado Perimetral:**<br>• **Centro de gravedad bajo** que otorga máxima estabilidad en curvas y evita volcadas.<br>• Transmisión mecánica directa y precisa en la dirección.<br>• Ultrasónicos a baja altura para detección exacta de paredes y límites de pista. |
---
## 🛠️ **Herramientas de Diseño y Fabricación Digital**
* **Software de Modelado CAD:** Autodesk Fusion 360 *(diseño paramétrico, ensamblaje virtual y verificación de tolerancias)*.
* **Tecnología de Fabricación:** Impresión 3D FDM de alta precisión en impresora **Bambu Lab** *(utilizando Bambu Studio)*.
* **Material Principal:** [PETG] *(alta rigidez estructural, resistencia a impactos y estabilidad térmica)*.

### 🎯 **Hoja de Ruta de Mejoras (Planes Futuros)**
* 🔄 **Independización de Potencia:** Integración de un regulador Step-Up dedicado exclusivamente al motor DC para que la demanda de corriente no afecte el voltaje del ESP32.
* 🔄 **Calibración de IMU:** Sustitución y calibración del giroscopio actual por uno de menor deriva (*drift*) para mayor precisión en la odometría de rumbo.

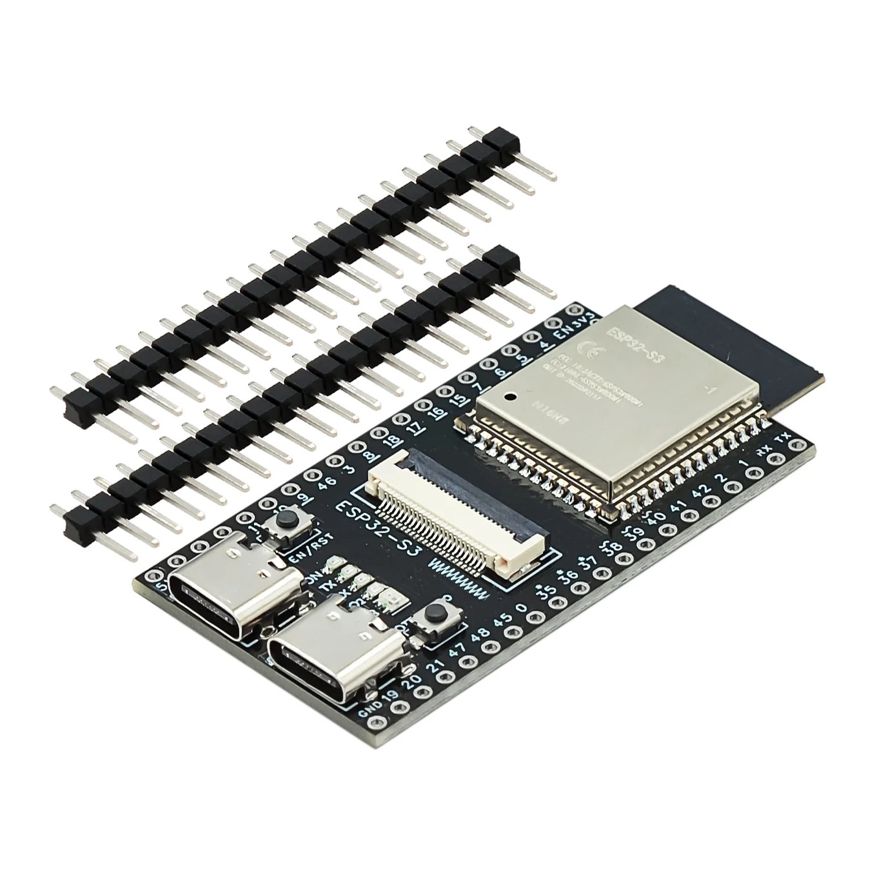
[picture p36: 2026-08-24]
Esquemas/ESP32-S3.jpeg

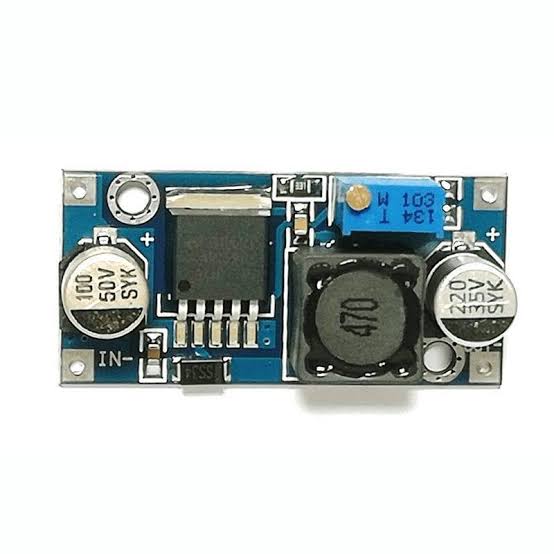
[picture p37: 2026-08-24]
Esquemas/LM2596.jpg

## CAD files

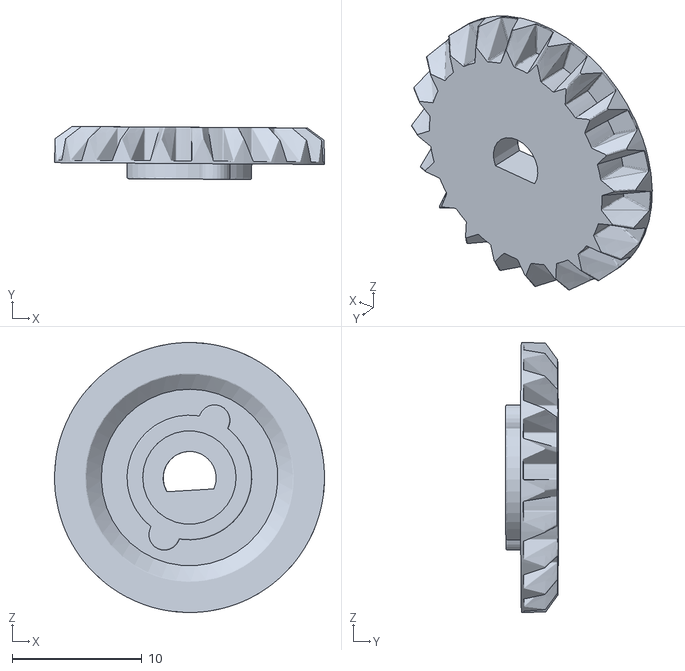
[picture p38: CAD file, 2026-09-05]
Modelos/ENGRANAJEM.stl
20.8 x 4.09 x 20.8

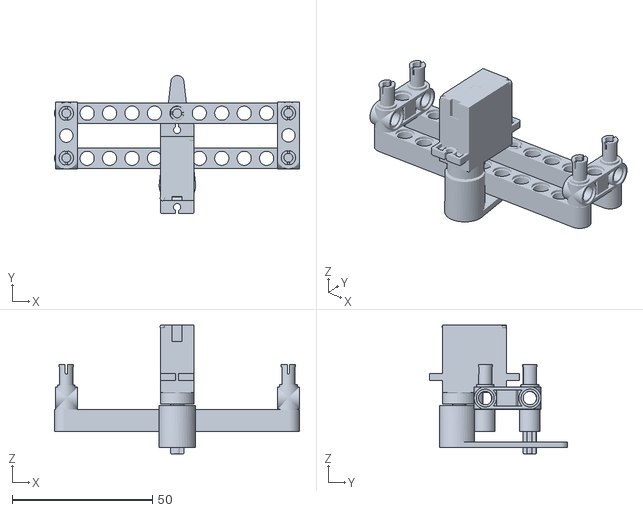
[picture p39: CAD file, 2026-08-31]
Modelos/Steering System.stl
87.4 x 49.2 x 46.0

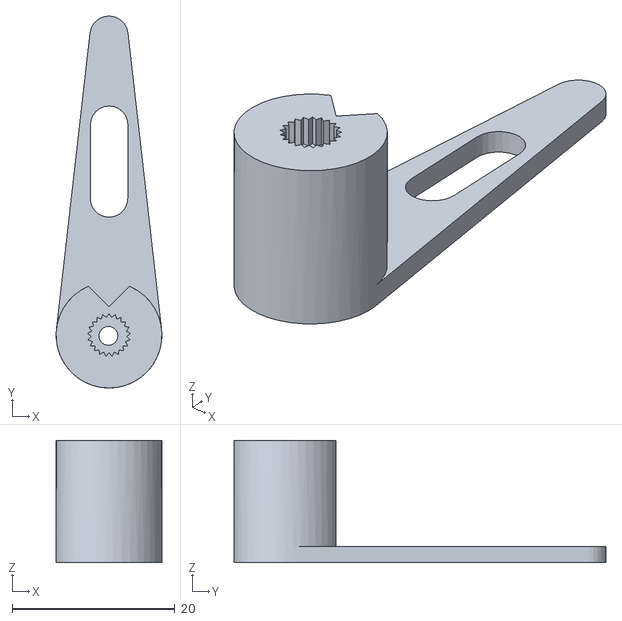
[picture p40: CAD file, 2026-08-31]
Modelos/Servor Arm.stl
13.0 x 45.7 x 15.0

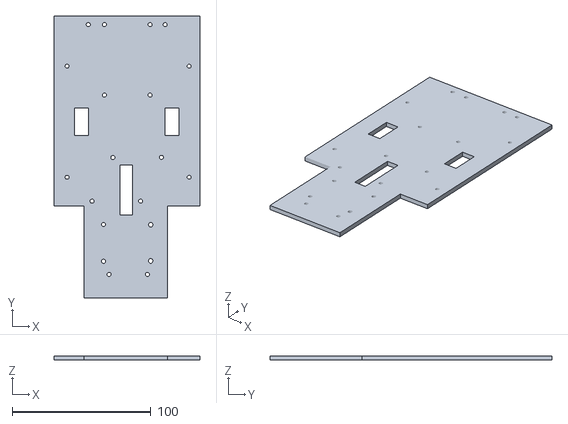
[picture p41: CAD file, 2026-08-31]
Modelos/Chassis Roof.stl
105.0 x 203.2 x 3.20

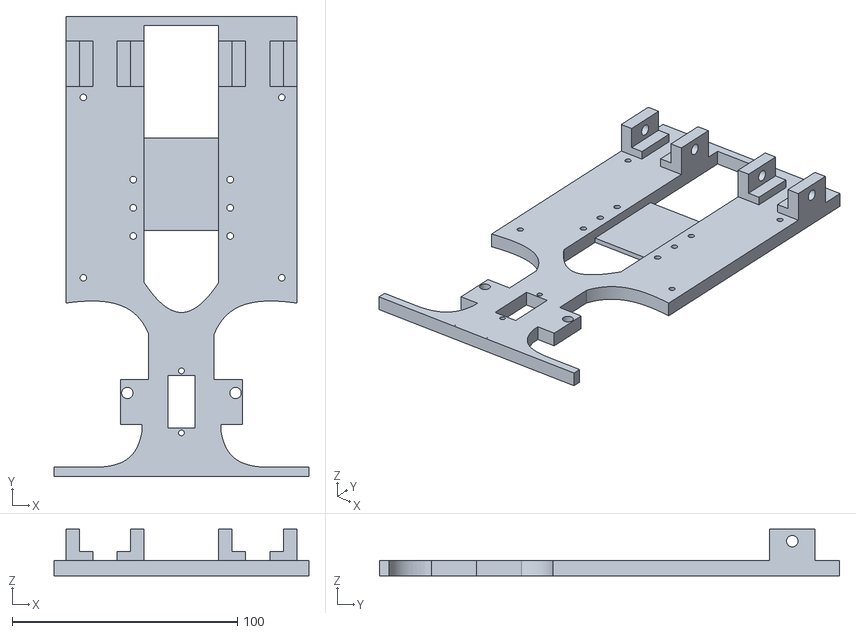
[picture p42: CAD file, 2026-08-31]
Modelos/Chassis.stl
113.0 x 204.0 x 20.7

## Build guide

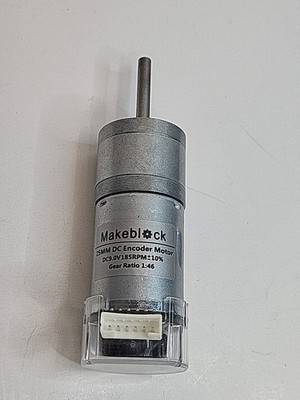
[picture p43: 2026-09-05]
Otro/Makeblock.jpg

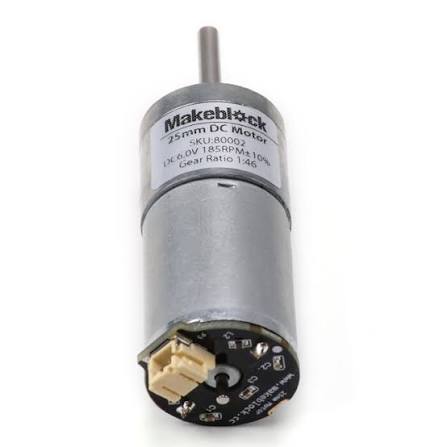
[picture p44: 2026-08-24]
Esquemas/Motor_Makeblock.jpg

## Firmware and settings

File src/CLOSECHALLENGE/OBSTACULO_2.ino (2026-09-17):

#include <Adafruit_MPU6050.h>
#include <Adafruit_Sensor.h>
#include <Wire.h>
#include <DFRobot_HuskylensV2.h> 

Adafruit_MPU6050 mpu;
HuskylensV2 huskylens;           
SET_LOOP_TASK_STACK_SIZE(16384);

// --- Pines ---
const int PIN_SERVO     = 8;
const int PIN_MOTOR_PWM = 15;
const int PIN_MOTOR_IN1 = 5;
const int PIN_MOTOR_IN2 = 6;
const int PIN_INICIO    = 21;

const int PIN_SDA = 16;
const int PIN_SCL = 17;

const int RX_HUSKY = 13;
const int TX_HUSKY = 12;

// Pines Ultrasónicos
const int PIN_TRIG_FRONTAL   = 42;
const int PIN_ECHO_FRONTAL   = 41;
const int PIN_TRIG_DERECHO   = 38;
const int PIN_ECHO_DERECHO   = 37;
const int PIN_TRIG_IZQUIERDO = 39;
const int PIN_ECHO_IZQUIERDO = 40;

// --- Panel de Tiempos Generales ---
const unsigned long TIEMPO_LECTURA_MS    = 1;
const unsigned long TIEMPO_CAMARA_MS     = 30; 
const unsigned long TIEMPO_SONAR_MS      = 50; 
const unsigned long TIEMPO_SERIAL_MS     = 100;

// --- Configuración Motor y Servo ---
const int SERVO_CENTRO  = 96;
const int MAX_DEFLEXION = 21;   
int VELOCIDAD_MOTOR     = 80;  

// =========================================================
// ---> PARAMETROS DE CABECEO (BÚSQUEDA DE CUBOS) <---
// =========================================================
bool HABILITAR_CABECEO       = true;    // Activa o desactiva la función
unsigned long TIEMPO_CABECEO = 1500;    // ms que dura haciendo el cabeceo al terminar maniobras
float AMPLITUD_CABECEO       = 40.0;    // Grados máximos hacia los que girará (amplitud del barrido)
float VELOCIDAD_CABECEO      = 0.006;   // Velocidad del vaivén (mayor = más rápido)
unsigned long TIEMPO_ESTABILIZACION = 300; // ms para calmar inercia antes de atacar el cubo

// =========================================================
// ---> CONTROL DE ESQUIVE VISUAL FLUIDO (CAZADOR) <---
// =========================================================
// FUERZAS INDEPENDIENTES (CENTRAR vs ESQUIVAR)
float KP_CENTRAR        = 0.005;  // Fuerza para perseguir y centrar el cubo desde lejos
float KP_ESQUIVE_ROJO   = 0.009;  // Fuerza del latigazo para esquivar ROJO
float KP_ESQUIVE_VERDE  = 0.010;  // Fuerza del latigazo para esquivar VERDE

// PARÁMETROS DE DISTANCIA (TAMAÑO)
int MIN_WIDTH_ESQUIVE    = 70;   // Menor a esto = lo ignora.
int WIDTH_INICIO_ESQUIVE = 180;  // Entre 60 y 150 SOLO LO CENTRA. A partir de 150 da el latigazo.
int WIDTH_CERCA          = 200;  
int BORDE_IZQ            = -100; // Objetivo extremo izquierdo
int BORDE_DER            = 740;  // Objetivo extremo derecho

unsigned long TIEMPO_ESCAPE = 100; // ms extra en diagonal para librar llantas traseras

// --- RETORNO CONSCIENTE Y SIMÉTRICO (POR COLORES) ---
// RETORNO BLOQUE ROJO (Pasa por Derecha, regresa a Izquierda)
float MULTIPLICADOR_ANGULO_RETORNO_ROJO = 2.0; 
float MULTIPLICADOR_TIEMPO_RETORNO_ROJO = 1.0; 
unsigned long MAX_TIEMPO_RETORNO_ROJO   = 2000; // <-- NUEVO: Tope máximo para el tiempo de regreso ROJO

// RETORNO BLOQUE VERDE (Pasa por Izquierda, regresa a Derecha)
float MULTIPLICADOR_ANGULO_RETORNO_VERDE = 2.0; 
float MULTIPLICADOR_TIEMPO_RETORNO_VERDE = 0.7; 
unsigned long MAX_TIEMPO_RETORNO_VERDE   = 2000; // <-- NUEVO: Tope máximo para el tiempo de regreso VERDE

// Memoria interna del robot para el cálculo
unsigned long tiempo_inicio_arrastre = 0;
unsigned long duracion_arrastre = 0;
float desviacion_memoria = 0.0;
unsigned long tiempo_retorno_dinamico = 0;

// --- FASES DESPUÉS DE ESQUIVAR (ALINEAR Y REVERSA) ---
unsigned long TIEMPO_ALINEACION           = 1000; // ms avanza recto permitiendo al PID enderezar el chasis
unsigned long TIEMPO_REVERSA_POST_ESQUIVE = 1300; // ms de reversa (después de alinear)
int VELOCIDAD_REVERSA_ESQUIVE             = 90;   // Velocidad de la reversa post-esquive

// --- COOLDOWNS POST-ESQUIVE Y POST-ESQUINA ---
unsigned long COOLDOWN_ENTRE_BLOQUES       = 400;  // ms de ceguera de CÁMARA tras esquivar un bloque
unsigned long COOLDOWN_POST_ESQUIVE        = 2000; // ms de ceguera de ULTRASONIDO tras esquivar
unsigned long COOLDOWN_CAMARA_POST_ESQUINA = 700;  // ms de ceguera de CÁMARA tras doblar esquina

// LÍMITES PARA IGNORAR BLOQUES YA LIBRADOS
int LIMITE_IGNORAR_ROJO       = 80;     
int LIMITE_IGNORAR_VERDE      = 560;   
unsigned long TIMEOUT_MEMORIA_CAMARA = 400; 

// =========================================================
// ---> CONTROL DE ESQUINAS Y ACOMODO (PAREDES) <---
// =========================================================
float DISTANCIA_GIRO          = 12.0;  
unsigned long TIEMPO_REVERSA  = 1900;  
int VELOCIDAD_REVERSA         = 140;   
float GRADOS_GIRO             = 89.8;  
unsigned long COOLDOWN_GIRO   = 3000;  
int MAX_DEFLEXION_ESQUINA     = 32;    

// --- Variables MPU ---
volatile float yaw_actual = 0.0;
volatile float gz_offset = 0.0;
unsigned long tiempo_anterior_mpu = 0;
TaskHandle_t TareaMPU;

// --- Variables de Control PD ---
float setpoint_yaw = 0.0;
float setpoint_base = 0.0; 
float error_anterior = 0.0;
int angulo_servo_actual = SERVO_CENTRO;

float Kp = 1.0;
float Kd = 0.0;

// --- Variables Lógica de Cámara Fluida ---
bool viendo_bloque = false;
unsigned long tiempo_ultima_vista = 0;
bool camara_conectada = false; 

bool en_escape = false;
unsigned long tiempo_inicio_escape = 0;
unsigned long tiempo_fin_escape = 0; 

bool en_retorno = false;
unsigned long tiempo_inicio_retorno = 0;

bool en_alineacion = false; 
unsigned long tiempo_inicio_alineacion = 0;

bool en_reversa_post_esquive = false;
unsigned long tiempo_inicio_reversa_esquive = 0;
unsigned long tiempo_fin_retorno = 0; 
int ultimo_id_visto = 0; 

int ancho_telemetria = 0;      
int target_x_telemetria = 320; 

// --- Variables de Cabeceo ---
bool en_cabeceo = false;
unsigned long tiempo_inicio_cabeceo = 0;
bool en_centrado_cabeceo = false;          
unsigned long tiempo_inicio_centrado = 0; 

// --- Variables Ultrasónico (Paredes) ---
float dist_frontal = 999.0, dist_derecha = 999.0, dist_izquierda = 999.0;
int turno_sensor = 0;

int direccion_global_pista = 0; 

bool en_acomodo = false;
bool esquina_alcanzada = false;
unsigned long tiempo_inicio_acomodo = 0;
unsigned long tiempo_fin_esquina = 0;
int direccion_esquina = 0; 

unsigned long tiempo_anterior = 0;
unsigned long tiempo_camara = 0;
unsigned long tiempo_sonar = 0;
unsigned long tiempo_serial = 0;
bool motor_encendido = false;

// ==========================================
// FUNCIONES
// ==========================================
void escribirServoGrados(int grados) {
  grados = constrain(grados, 0, 180);
  int duty = map(grados, 0, 180, 102, 491);
  ledcWrite(PIN_SERVO, duty);
}

float medirDistancia(int pinTrig, int pinEcho) {
  digitalWrite(pinTrig, LOW); delayMicroseconds(2);
  digitalWrite(pinTrig, HIGH); delayMicroseconds(10);
  digitalWrite(pinTrig, LOW);
  long duracion = pulseIn(pinEcho, HIGH, 15000); 
  if (duracion == 0) return 999.0;
  return (duracion * 0.0343) / 2.0;
}

void rescatarBusI2C() {
  Wire.end();
  pinMode(PIN_SDA, INPUT_PULLUP); pinMode(PIN_SCL, OUTPUT);
  for (int i = 0; i < 9; i++) {
    digitalWrite(PIN_SCL, LOW); delayMicroseconds(10);
    digitalWrite(PIN_SCL, HIGH); delayMicroseconds(10);
    if (digitalRead(PIN_SDA) == HIGH) break;
  }
  pinMode(PIN_SDA, OUTPUT);
  digitalWrite(PIN_SDA, LOW); delayMicroseconds(10);
  digitalWrite(PIN_SCL, HIGH); delayMicroseconds(10);
  digitalWrite(PIN_SDA, HIGH); delayMicroseconds(10);
  Wire.begin(PIN_SDA, PIN_SCL);
  Wire.setClock(100000);
  Wire.setTimeout(50);
  mpu.begin(0x68, &Wire);
  mpu.setGyroRange(MPU6050_RANGE_1000_DEG);
  mpu.setFilterBandwidth(MPU6050_BAND_21_HZ);
}

bool leerMPUSeguro(float &gz_out) {
  Wire.beginTransmission(0x68);
  if (Wire.endTransmission(true) != 0) { rescatarBusI2C(); return false; }
  sensors_event_t a, g, temp;
  mpu.getEvent(&a, &g, &temp);
  gz_out = (g.gyro.z - gz_offset) * (180.0 / PI);
  return true;
}

void tareaLeerMPU(void * parameter) {
  for (;;) {
    unsigned long tiempo_ahora = millis();
    float dt = (tiempo_ahora - tiempo_anterior_mpu) / 1000.0;
    tiempo_anterior_mpu = tiempo_ahora;
    if (dt <= 0) dt = 0.002;
    if (dt > 0.05) dt = 0.05;
    float gz = 0.0;
    if (leerMPUSeguro(gz)) {
      if (abs(gz) > 0.3) yaw_actual += gz * dt;
    }
    vTaskDelay(2 / portTICK_PERIOD_MS);
  }
}

void setup() {
  pinMode(PIN_MOTOR_IN1, OUTPUT); 
  pinMode(PIN_MOTOR_IN2, OUTPUT);
  digitalWrite(PIN_MOTOR_IN1, LOW); 
  digitalWrite(PIN_MOTOR_IN2, LOW);
  
  ledcAttach(PIN_MOTOR_PWM, 1000, 8); 
  ledcWrite(PIN_MOTOR_PWM, 0); 
  
  ledcAttach(PIN_SERVO, 50, 12); 
  escribirServoGrados(SERVO_CENTRO); 

  Serial.begin(115200);
  Serial1.begin(115200, SERIAL_8N1, RX_HUSKY, TX_HUSKY); 
  
  Wire.begin(PIN_SDA, PIN_SCL);
  Wire.setClock(100000);
  Wire.setTimeout(50);

  pinMode(PIN_INICIO, INPUT_PULLDOWN);
  pinMode(PIN_TRIG_FRONTAL, OUTPUT); pinMode(PIN_ECHO_FRONTAL, INPUT);
  pinMode(PIN_TRIG_DERECHO, OUTPUT); pinMode(PIN_ECHO_DERECHO, INPUT);
  pinMode(PIN_TRIG_IZQUIERDO, OUTPUT); pinMode(PIN_ECHO_IZQUIERDO, INPUT);
  
  Serial.println("Iniciando MPU6050...");
  mpu.begin(0x68, &Wire);
  mpu.setGyroRange(MPU6050_RANGE_1000_DEG); 
  mpu.setFilterBandwidth(MPU6050_BAND_21_HZ); 
  
  Serial.println("PULSA EL BOTON PARA ARRANCAR...");
  Serial.println("(Buscando cámara HuskyLens en segundo plano...)");
  
  unsigned long t_reintento = 0;
  while (digitalRead(PIN_INICIO) == LOW) { 
    if (!camara_conectada && millis() - t_reintento > 500) {
      t_reintento = millis();
      if (huskylens.begin(Serial1)) {
        Serial.println("¡HuskyLens CONECTADA exitosamente!");
        huskylens.switchAlgorithm(ALGORITHM_OBJECT_TRACKING);
        camara_conectada = true;
      }
    }
    delay(10); 
  }

  Serial.println("Calibrando MPU...");
  delay(100); 
  float suma_gz = 0;
  for (int i = 0; i < 50; i++) { 
    sensors_event_t a, g, temp;
    mpu.getEvent(&a, &g, &temp);
    suma_gz += g.gyro.z;
    delay(10);
  }
  gz_offset = suma_gz / 50.0; 
  tiempo_anterior_mpu = millis();

  xTaskCreatePinnedToCore(tareaLeerMPU, "TareaMPU", 4096, NULL, 2, &TareaMPU, 0);
  
  delay(10);
  digitalWrite(PIN_MOTOR_IN1, HIGH); digitalWrite(PIN_MOTOR_IN2, LOW);
  ledcWrite(PIN_MOTOR_PWM, VELOCIDAD_MOTOR);
  motor_encendido = true;
  tiempo_anterior = millis();
  tiempo_camara = millis();
  tiempo_sonar = millis();
  tiempo_serial = millis();
  
  setpoint_base = 0.0; 
  direccion_global_pista = 0; 
  
  Serial.println(">>> MODO ARRASTRE FLUIDO (CAZADOR + PAREDES) <<<");
}

void loop() {
  unsigned long tiempo_actual = millis();

  // ========================================================
  // 1. MANIOBRA DE ACOMODO EN REVERSA (PAREDES)
  // ========================================================
  if (en_acomodo) {
    
    if (!esquina_alcanzada) {
      float error_esquina = setpoint_yaw - yaw_actual; 
      if (abs(error_esquina) < 7.0) { 
        esquina_alcanzada = true;
      }
    }

    if (esquina_alcanzada) {
      escribirServoGrados(SERVO_CENTRO);
    } else {
      if (direccion_esquina == 1) escribirServoGrados(SERVO_CENTRO - MAX_DEFLEXION_ESQUINA); 
      else escribirServoGrados(SERVO_CENTRO + MAX_DEFLEXION_ESQUINA); 
    }

    if (tiempo_actual - tiempo_inicio_acomodo >= TIEMPO_REVERSA) {
      digitalWrite(PIN_MOTOR_IN1, HIGH); 
      digitalWrite(PIN_MOTOR_IN2, LOW); 
      ledcWrite(PIN_MOTOR_PWM, VELOCIDAD_MOTOR);

      en_acomodo = false;
      tiempo_fin_esquina = tiempo_actual;

      // Iniciar el cabeceo al terminar la esquina
      if (HABILITAR_CABECEO) {
        en_cabeceo = true;
        tiempo_inicio_cabeceo = tiempo_actual;
      }
    }
  }

  // ========================================================
  // 2. CÁMARA: ARRASTRE FLUIDO (Cada 30 ms)
  // ========================================================
  else if (motor_encendido && !en_acomodo && (tiempo_actual - tiempo_camara >= TIEMPO_CAMARA_MS)) {
    tiempo_camara = tiempo_actual;
    
    // --- FASE 4: REVERSA POST-ESQUIVE ---
    if (en_reversa_post_esquive) {
      escribirServoGrados(SERVO_CENTRO); 
      
      if (tiempo_actual - tiempo_inicio_reversa_esquive >= TIEMPO_REVERSA_POST_ESQUIVE) {
        en_reversa_post_esquive = false;
        tiempo_fin_retorno = tiempo_actual; 
        
        digitalWrite(PIN_MOTOR_IN1, HIGH); 
        digitalWrite(PIN_MOTOR_IN2, LOW); 
        ledcWrite(PIN_MOTOR_PWM, VELOCIDAD_MOTOR);

        // Iniciar el cabeceo al terminar de esquivar
        if (HABILITAR_CABECEO) {
          en_cabeceo = true;
          tiempo_inicio_cabeceo = tiempo_actual;
        }
      }
    }

    // --- FASE 3: ALINEACIÓN PRE-REVERSA ---
    if (en_alineacion) {
      if (tiempo_actual - tiempo_inicio_alineacion >= TIEMPO_ALINEACION) {
        en_alineacion = false;
        
        en_reversa_post_esquive = true;
        tiempo_inicio_reversa_esquive = tiempo_actual;
        
        digitalWrite(PIN_MOTOR_IN1, LOW); 
        digitalWrite(PIN_MOTOR_IN2, HIGH); 
        ledcWrite(PIN_MOTOR_PWM, VELOCIDAD_REVERSA_ESQUIVE);
      }
    }

    // --- FASE 2: RETORNO CONSCIENTE ---
    if (en_retorno && !en_alineacion && !en_reversa_post_esquive) {
      if (tiempo_actual - tiempo_inicio_retorno >= tiempo_retorno_dinamico) {
        en_retorno = false;
        
        setpoint_yaw = setpoint_base; 
        
        en_alineacion = true;
        tiempo_inicio_alineacion = tiempo_actual;
      }
    }

    // --- FASE 1: ESCAPE DE SEGURIDAD ---
    if (en_escape) {
      if (tiempo_actual - tiempo_inicio_escape >= TIEMPO_ESCAPE) {
        en_escape = false;
        en_retorno = true;
        tiempo_inicio_retorno = tiempo_actual;
        tiempo_fin_escape = tiempo_actual; 
        
        // ¡LA MAGIA SEPARADA POR COLORES (Y CON LÍMITES)!
        if (ultimo_id_visto == 1) { // ROJO
          setpoint_yaw = setpoint_base - (desviacion_memoria * MULTIPLICADOR_ANGULO_RETORNO_ROJO);
          tiempo_retorno_dinamico = (duracion_arrastre + TIEMPO_ESCAPE) * MULTIPLICADOR_TIEMPO_RETORNO_ROJO;
          if (tiempo_retorno_dinamico > MAX_TIEMPO_RETORNO_ROJO) {
            tiempo_retorno_dinamico = MAX_TIEMPO_RETORNO_ROJO;
          }
        } else if (ultimo_id_visto == 2) { // VERDE
          setpoint_yaw = setpoint_base - (desviacion_memoria * MULTIPLICADOR_ANGULO_RETORNO_VERDE);
          tiempo_retorno_dinamico = (duracion_arrastre + TIEMPO_ESCAPE) * MULTIPLICADOR_TIEMPO_RETORNO_VERDE;
          if (tiempo_retorno_dinamico > MAX_TIEMPO_RETORNO_VERDE) {
            tiempo_retorno_dinamico = MAX_TIEMPO_RETORNO_VERDE;
          }
        }
      }
    }

    // --- FASE DE CABECEO (BÚSQUEDA) ---
    if (en_cabeceo && !en_reversa_post_esquive) {
      unsigned long tiempo_transcurrido = tiempo_actual - tiempo_inicio_cabeceo;
      
      if (tiempo_transcurrido >= TIEMPO_CABECEO) {
        en_cabeceo = false;
        setpoint_yaw = setpoint_base; // Retorna a ruta recta
      } else {
        // Genera el vaivén usando la función matemática seno
        float desviacion = sin(tiempo_transcurrido * VELOCIDAD_CABECEO) * AMPLITUD_CABECEO;
        setpoint_yaw = setpoint_base + desviacion;
      }
    }

    // --- NUEVO: FASE DE ESTABILIZACIÓN POST-CABECEO ---
    if (en_centrado_cabeceo) {
      if (tiempo_actual - tiempo_inicio_centrado >= TIEMPO_ESTABILIZACION) {
        en_centrado_cabeceo = false;
      } else {
        setpoint_yaw = setpoint_base; // Obliga al volante a estar centrado para matar inercia
      }
    }
    
    bool bloque_visto_ahora = false;
    int x_actual = -1;
    int width_actual = -1;
    int id_actual = -1;
    
    bool cooldown_bloques_pasado = (tiempo_actual - tiempo_fin_retorno > COOLDOWN_ENTRE_BLOQUES);
    bool cooldown_camara_esquina_pasado = (tiempo_actual - tiempo_fin_esquina > COOLDOWN_CAMARA_POST_ESQUINA);

    // OJO: Permitimos que la cámara lea aunque estemos en cabeceo, esa es la meta
    if (camara_conectada && !en_escape && !en_retorno && !en_alineacion && !en_reversa_post_esquive && cooldown_bloques_pasado && cooldown_camara_esquina_pasado && huskylens.getResult(ALGORITHM_OBJECT_TRACKING)) {
      while (huskylens.available(ALGORITHM_OBJECT_TRACKING)) {
        Result *result = static_cast<Result *>(huskylens.popCachedResult(ALGORITHM_OBJECT_TRACKING));
        
        bool ignorar = false;
        
        if (result->width < MIN_WIDTH_ESQUIVE) ignorar = true; // Si está muy lejos, se ignora por completo
        
        if (result->ID == 1 && result->xCenter < LIMITE_IGNORAR_ROJO) ignorar = true;
        if (result->ID == 2 && result->xCenter > LIMITE_IGNORAR_VERDE) ignorar = true;

        if (!ignorar && (result->ID == 1 || result->ID == 2) && result->width > width_actual) {
          width_actual = result->width;
          x_actual = result->xCenter;
          id_actual = result->ID;
          bloque_visto_ahora = true;
        }
      }

      if (bloque_visto_ahora) {
        
        // --- INTERRUPCIÓN DE CABECEO Y ACTIVACIÓN DE ESTABILIZACIÓN ---
        if (en_cabeceo) {
          en_cabeceo = false;
          en_centrado_cabeceo = true;
          tiempo_inicio_centrado = tiempo_actual;
          setpoint_yaw = setpoint_base;
        }

        // Siempre registramos que vimos el bloque para no perder memoria
        tiempo_ultima_vista = tiempo_actual;
        ultimo_id_visto = id_actual; 
        ancho_telemetria = width_actual; 
        
        // SOLO iniciamos el control visual si NO estamos estabilizando la inercia
        if (!en_centrado_cabeceo) {

          if (!viendo_bloque) {
            viendo_bloque = true;
            tiempo_inicio_arrastre = tiempo_actual; // Inicia el cronómetro visual
          }

          // --- FASE 1: CENTRAR (Cazar) vs FASE 2: ESQUIVAR (Latigazo) ---
          int target_x = 320;
          float kp_actual = KP_CENTRAR; 
          
          if (width_actual <= WIDTH_INICIO_ESQUIVE) {
            // MODO CENTRAR: Fija la mira exactamente en el centro (320)
            target_x = 320;
            kp_actual = KP_CENTRAR;
          } else {
            // MODO ESQUIVAR: Empieza a aventarlo hacia los bordes
            int width_mapeado = constrain(width_actual, WIDTH_INICIO_ESQUIVE, WIDTH_CERCA);
            if (id_actual == 1) { 
              target_x = map(width_mapeado, WIDTH_INICIO_ESQUIVE, WIDTH_CERCA, 320, BORDE_IZQ);
              kp_actual = KP_ESQUIVE_ROJO;
            } else if (id_actual == 2) { 
              target_x = map(width_mapeado, WIDTH_INICIO_ESQUIVE, WIDTH_CERCA, 320, BORDE_DER);
              kp_actual = KP_ESQUIVE_VERDE;
            }
          }
          
          target_x_telemetria = target_x; 

          float error_x = target_x - (float)x_actual;
          setpoint_yaw += (error_x * kp_actual); 
        }
      }
    }
    
    if (!bloque_visto_ahora) {
      ancho_telemetria = 0; 
      
      if (viendo_bloque) {
        if (tiempo_actual - tiempo_ultima_vista > TIMEOUT_MEMORIA_CAMARA) {
          viendo_bloque = false; 

          // --- GUARDAR MEMORIA FINAL DEL ESQUIVE ANTES DE ESCAPAR ---
          duracion_arrastre = tiempo_actual - tiempo_inicio_arrastre; // Cuánto tiempo duró abierto
          desviacion_memoria = setpoint_yaw - setpoint_base; // Cuántos grados se alejó del carril original

          en_escape = true; 
          tiempo_inicio_escape = tiempo_actual;
        }
      }
    }
  }

  // ========================================================
  // 3. SENSORES ULTRASÓNICOS (PAREDES) (Cada 50 ms)
  // ========================================================
  if (motor_encendido && !en_acomodo && (tiempo_actual - tiempo_sonar >= TIEMPO_SONAR_MS)) {
    tiempo_sonar = tiempo_actual;
    
    if (turno_sensor == 0) dist_frontal = medirDistancia(PIN_TRIG_FRONTAL, PIN_ECHO_FRONTAL);
    else if (turno_sensor == 1) dist_derecha = medirDistancia(PIN_TRIG_DERECHO, PIN_ECHO_DERECHO);
    else dist_izquierda = medirDistancia(PIN_TRIG_IZQUIERDO, PIN_ECHO_IZQUIERDO);
    
    turno_sensor = (turno_sensor + 1) % 3;

    bool cooldown_pasado = (tiempo_actual - tiempo_fin_esquina > COOLDOWN_GIRO);
    bool cooldown_post_esquive_pasado = (tiempo_actual - tiempo_fin_escape > COOLDOWN_POST_ESQUIVE);

    if (cooldown_pasado && cooldown_post_esquive_pasado && !viendo_bloque && !en_escape && !en_retorno && !en_alineacion && !en_reversa_post_esquive && dist_frontal <= DISTANCIA_GIRO) {
      
      if (direccion_global_pista == 0) {
        if (dist_izquierda >= dist_derecha) {
          direccion_global_pista = 1;  
          Serial.println("\n[PISTA] IZQUIERDAS.");
        } else {
          direccion_global_pista = -1; 
          Serial.println("\n[PISTA] DERECHAS.");
        }
      }
      
      direccion_esquina = direccion_global_pista; 
      
      en_acomodo = true;
      esquina_alcanzada = false; 
      tiempo_inicio_acomodo = tiempo_actual;
      dist_frontal = 999.0; 

      if (direccion_esquina == 1) {
        setpoint_yaw -= GRADOS_GIRO;
        setpoint_base -= GRADOS_GIRO;
      } else {
        setpoint_yaw += GRADOS_GIRO;
        setpoint_base += GRADOS_GIRO;
      }

      digitalWrite(PIN_MOTOR_IN1, LOW); 
      digitalWrite(PIN_MOTOR_IN2, HIGH); 
      ledcWrite(PIN_MOTOR_PWM, VELOCIDAD_REVERSA);
      
      if (direccion_esquina == 1) escribirServoGrados(SERVO_CENTRO - MAX_DEFLEXION_ESQUINA); 
      else escribirServoGrados(SERVO_CENTRO + MAX_DEFLEXION_ESQUINA); 
    }
  }

  // ========================================================
  // 4. CONTROL DE DIRECCIÓN MPU (Cada 1 ms)
  // ========================================================
  if (motor_encendido && !en_acomodo && !en_reversa_post_esquive && (tiempo_actual - tiempo_anterior >= TIEMPO_LECTURA_MS)) {
    float dt = (tiempo_actual - tiempo_anterior) / 1000.0;
    if (dt == 0) dt = 0.001;
    tiempo_anterior = tiempo_actual;

    float error = setpoint_yaw - yaw_actual;
    if (abs(error) < 2.0) { 
      error = 0.0; 
      error_anterior = 0.0; 
    }

    float derivada = (error - error_anterior) / dt;
    error_anterior = error;
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

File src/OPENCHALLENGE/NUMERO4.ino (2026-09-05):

#include <Adafruit_MPU6050.h>
#include <Adafruit_Sensor.h>
#include <Wire.h>

Adafruit_MPU6050 mpu;
SET_LOOP_TASK_STACK_SIZE(16384);

// --- Pines ---
const int PIN_SERVO     = 8;
const int PIN_MOTOR_PWM = 15;
const int PIN_MOTOR_IN1 = 5;
const int PIN_MOTOR_IN2 = 6;
const int PIN_INICIO    = 21;

const int PIN_SDA = 16;
const int PIN_SCL = 17;

const int PIN_TRIG_FRONTAL   = 42;
const int PIN_ECHO_FRONTAL   = 41;
const int PIN_TRIG_DERECHO   = 38;
const int PIN_ECHO_DERECHO   = 37;
const int PIN_TRIG_IZQUIERDO = 39;
const int PIN_ECHO_IZQUIERDO = 40;

// --- Panel de Tiempos ---
const unsigned long TIEMPO_LECTURA_MS    = 1;
const unsigned long TIEMPO_SONAR_MS      = 50;
const unsigned long TIEMPO_SERIAL_MS     = 100;
const unsigned long TIEMPO_ESPERA_MOTOR  = 10;

// --- Configuración Servo ---
const int SERVO_CENTRO  = 96;
const int MAX_DEFLEXION = 21;

// =========================================================
// VARIABLES AJUSTABLES PARA CALIBRAR
// =========================================================
float DISTANCIA_GIRO          = 70.0;  
float GRADOS_GIRO             = 89.0;  
unsigned long COOLDOWN_GIRO_MS = 500; 

// ---> DISTANCIA LIBRE LATERAL (Aplica para el lado que elija) <---
float DISTANCIA_LIBRE_LATERAL = 70.0;  

float DISTANCIA_MIN_LATERAL   = 25.0;  
float ANGULO_ESCAPE           = 25.0;  

// ---> CONTROL DE TIEMPOS DE ARRANQUE Y MANIOBRAS <---
int MUESTRAS_CALIBRACION_MPU         = 50;   // Cantidad de lecturas para calibrar
unsigned long TIEMPO_PRE_CALIBRACION = 100;  // ms: Pausa ANTES de calibrar el MPU
unsigned long TIEMPO_CEGUERA_INICIAL = 500;  // ms: Tiempo rodando sin detectar esquinas al arrancar
unsigned long TIMEOUT_GIRO           = 2500; // ms: Tiempo máximo que puede durar un giro
unsigned long TIEMPO_PARO_FIN        = 1500; // ms: Tiempo para apagar motores tras la esquina 12
// =========================================================

// --- Variables MPU ---
volatile float yaw_actual = 0.0;
volatile float gz_offset = 0.0;
unsigned long tiempo_anterior_mpu = 0;
TaskHandle_t TareaMPU;

// --- Variables de Control PD ---
float setpoint_yaw = 0.0;
float offset_lateral = 0.0;
float error_anterior = 0.0;
int angulo_servo_actual = SERVO_CENTRO;

float Kp = 1.0;
float Kd = 0.0;
const float ZONA_MUERTA = 2.0;

// --- Variables Ultrasónico ---
float dist_frontal   = 999.0;
float dist_derecha   = 999.0;
float dist_izquierda = 999.0;
int turno_sensor = 0;

bool en_maniobra = false;
unsigned long tiempo_inicio_giro = 0;
unsigned long tiempo_fin_maniobra = 0;

// --- Variables de Carrera y Dirección ---
int esquinas_contadas = 0;
int direccion_giro = 0; 
bool carrera_terminada = false;
bool motor_frenado = false;
unsigned long tiempo_fin_carrera = 0;

unsigned long tiempo_anterior = 0;
unsigned long tiempo_sonar = 0;
unsigned long tiempo_serial = 0;
unsigned long tiempo_inicio_motor = 0;
bool motor_encendido = false;

// ==========================================
// FUNCIONES
// ==========================================
void escribirServoGrados(int grados) {
  grados = constrain(grados, 0, 180);
  int duty = map(grados, 0, 180, 102, 491);
  ledcWrite(PIN_SERVO, duty);
}

float medirDistancia(int pinTrig, int pinEcho) {
  digitalWrite(pinTrig, LOW); delayMicroseconds(2);
  digitalWrite(pinTrig, HIGH); delayMicroseconds(10);
  digitalWrite(pinTrig, LOW);
  long duracion = pulseIn(pinEcho, HIGH, 15000); 
  if (duracion == 0) return 999.0;
  return (duracion * 0.0343) / 2.0;
}

void rescatarBusI2C() {
  Wire.end();
  pinMode(PIN_SDA, INPUT_PULLUP); pinMode(PIN_SCL, OUTPUT);
  for (int i = 0; i < 9; i++) {
    digitalWrite(PIN_SCL, LOW); delayMicroseconds(10);
    digitalWrite(PIN_SCL, HIGH); delayMicroseconds(10);
    if (digitalRead(PIN_SDA) == HIGH) break;
  }
  pinMode(PIN_SDA, OUTPUT);
  digitalWrite(PIN_SDA, LOW); delayMicroseconds(10);
  digitalWrite(PIN_SCL, HIGH); delayMicroseconds(10);
  digitalWrite(PIN_SDA, HIGH); delayMicroseconds(10);
  Wire.begin(PIN_SDA, PIN_SCL);
  Wire.setClock(100000);
  Wire.setTimeout(50);
  mpu.begin(0x68, &Wire);
  mpu.setGyroRange(MPU6050_RANGE_1000_DEG);
  mpu.setFilterBandwidth(MPU6050_BAND_21_HZ);
}

bool leerMPUSeguro(float &gz_out) {
  Wire.beginTransmission(0x68);
  if (Wire.endTransmission(true) != 0) { rescatarBusI2C(); return false; }
  sensors_event_t a, g, temp;
  mpu.getEvent(&a, &g, &temp);
  gz_out = (g.gyro.z - gz_offset) * (180.0 / PI);
  return true;
}

void tareaLeerMPU(void * parameter) {
  for (;;) {
    unsigned long tiempo_ahora = millis();
    float dt = (tiempo_ahora - tiempo_anterior_mpu) / 1000.0;
    tiempo_anterior_mpu = tiempo_ahora;
    if (dt <= 0) dt = 0.002;
    if (dt > 0.05) dt = 0.05;
    float gz = 0.0;
    if (leerMPUSeguro(gz)) {
      if (abs(gz) > 0.3) yaw_actual += gz * dt;
    }
    vTaskDelay(2 / portTICK_PERIOD_MS);
  }
}

void setup() {
  // 1. BLOQUE DE EMERGENCIA: APAGAR TODO ANTES DE HACER CUALQUIER OTRA COSA
  pinMode(PIN_MOTOR_IN1, OUTPUT); 
  pinMode(PIN_MOTOR_IN2, OUTPUT);
  digitalWrite(PIN_MOTOR_IN1, LOW); 
  digitalWrite(PIN_MOTOR_IN2, LOW);
  
  ledcAttach(PIN_MOTOR_PWM, 1000, 8); 
  ledcWrite(PIN_MOTOR_PWM, 0); // Forzar motor a velocidad cero
  
  ledcAttach(PIN_SERVO, 50, 12); 
  escribirServoGrados(SERVO_CENTRO); // Clavar el servo al centro inmediatamente

  // 2. INICIAR COMUNICACIONES (Ahora es seguro porque los motores ya están bloqueados)
  Serial.begin(115200);
  Wire.begin(PIN_SDA, PIN_SCL);
  Wire.setClock(100000);
  Wire.setTimeout(50);

  // 3. INICIAR SENSORES Y BOTÓN
  pinMode(PIN_INICIO, INPUT_PULLDOWN);
  pinMode(PIN_TRIG_FRONTAL, OUTPUT); pinMode(PIN_ECHO_FRONTAL, INPUT);
  pinMode(PIN_TRIG_DERECHO, OUTPUT); pinMode(PIN_ECHO_DERECHO, INPUT);
  pinMode(PIN_TRIG_IZQUIERDO, OUTPUT); pinMode(PIN_ECHO_IZQUIERDO, INPUT);
  
  Serial.println("Iniciando MPU6050...");
  mpu.begin(0x68, &Wire);
  mpu.setGyroRange(MPU6050_RANGE_1000_DEG); 
  mpu.setFilterBandwidth(MPU6050_BAND_21_HZ); 
  
  Serial.println("Esperando senal pin 21 para arrancar...");
  while (digitalRead(PIN_INICIO) == LOW) { delay(100); }

  Serial.println("Calibrando MPU... NO TOQUES EL CARRO!");
  delay(TIEMPO_PRE_CALIBRACION); 
  
  float suma_gz = 0;
  for (int i = 0; i < MUESTRAS_CALIBRACION_MPU; i++) { 
    sensors_event_t a, g, temp;
    mpu.getEvent(&a, &g, &temp);
    suma_gz += g.gyro.z;
    delay(10);
  }
  gz_offset = suma_gz / (float)MUESTRAS_CALIBRACION_MPU; 
  tiempo_anterior_mpu = millis();

  xTaskCreatePinnedToCore(tareaLeerMPU, "TareaMPU", 4096, NULL, 2, &TareaMPU, 0);
  
  delay(TIEMPO_ESPERA_MOTOR);
  
  digitalWrite(PIN_MOTOR_IN1, HIGH); digitalWrite(PIN_MOTOR_IN2, LOW);
  ledcWrite(PIN_MOTOR_PWM, 255);
  motor_encendido = true;
  tiempo_inicio_motor = millis();
  tiempo_anterior = millis();
  
  Serial.println("SISTEMA ACTIVO: DETECCIÓN INTELIGENTE DE 1RA ESQUINA (12 VUELTAS)");
}
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

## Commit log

2026-08-24 Create Modelos
    Creación de apartado de modelos
2026-09-11 Corregir formato y visualizacion de tablas Markdown
2026-09-11 docs: actualizar nomenclatura a Modulos, anadir mitigacion de riesgos, curva par-velocidad y rediseño veleta servo
2026-09-11 docs: detallar anatomia del brazo de servo custom, colisa anti-atasco y render BRAZOSERVO.jpg
2026-09-11 fix: simplificar visualizacion de formula delta r a formato unicode
2026-09-11 docs: anadir seccion 1.7.1 de evolucion y autopsia tecnica de prototipos descartados
2026-09-14 docs: anadir seccion de seleccion de cableado 18 awg automotriz y conexion por borneras
2026-09-15 docs: anadir seccion de simulacion cinematica en matlab/octave para mathworks modeling award
2026-09-15 docs: alinear documentacion con palabras clave de la rubrica oficial WRO 2026 (30/30 pts)
2026-09-15 docs: retirar cuadro explicito de rubrica manteniendo palabras clave integradas en el texto
2026-09-15 docs: anadir badges de MATLAB y MathWorks Modeling Award al encabezado y seccion 3.5
2026-09-17 docs: integrar fotos del proceso constructivo, ensamble mecanico, cableado y detras de camaras
2026-09-17 fix(docs): corregir renderizado de delta y espaciado de ecuaciones matematicas de Ackermann
